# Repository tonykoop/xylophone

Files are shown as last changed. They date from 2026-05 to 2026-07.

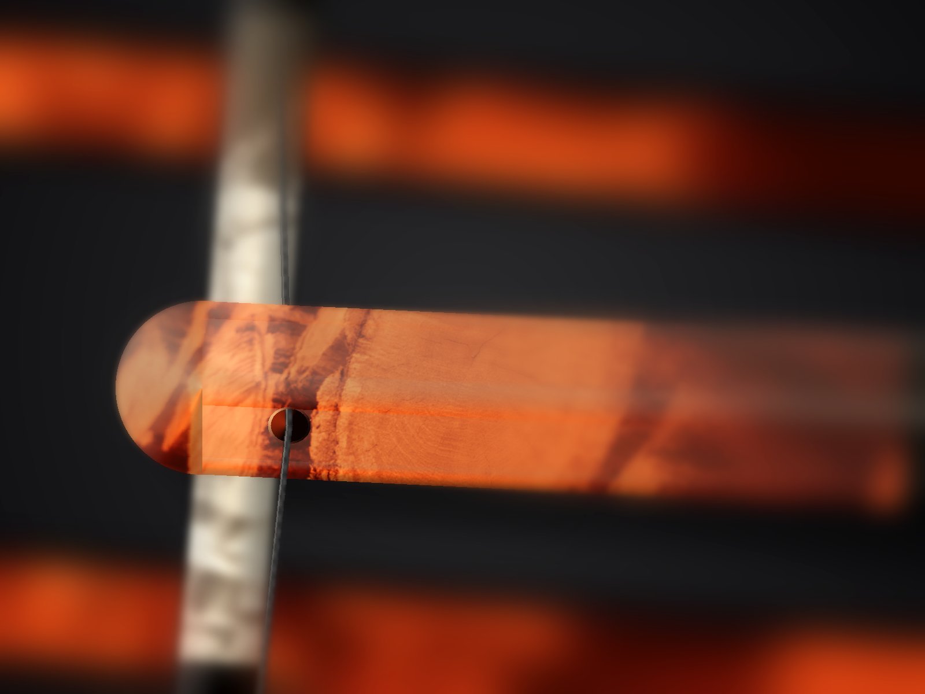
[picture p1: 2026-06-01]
images/macro/node-hole-suspension.png

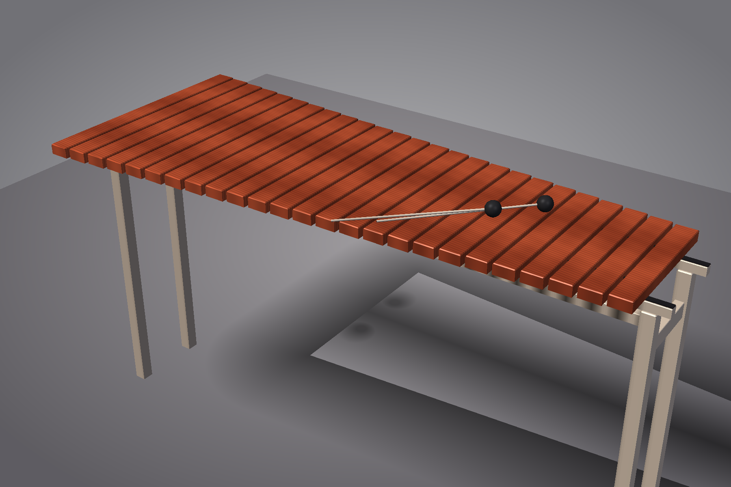
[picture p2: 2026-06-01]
images/hero-render.png

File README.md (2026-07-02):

# Xylophone

**Status:** L2 V5 build-packet candidate. Full design table, BOM, sourcing,
cut-list, and validation-loop gates exist for all 25 bars, but every bar
length, node-hole position, and resonator length is `measurement_required`
until a pilot bar is cut, tuned, mounted, and logged — see "Round 31 V5
Build-Packet Gate" below.

Xylophone hero — 25-bar chromatic in Padauk on a parametric trestle frame (placeholder)

A 25-bar chromatic xylophone, **C5 to C7**, in African Padauk on a
parametric trestle frame. Free-free flat-bar geometry, 12th-overtone
tuning convention, optional quarter-wave closed-pipe resonators
(deferred to v2). This repo is a v4.3 root-mode build packet from the
[`tonykoop/instrument-maker`](https://github.com/tonykoop/instrument-maker)
catalogue, designed deliberately as the *simpler sibling* of a future
`tonykoop/marimba` repo.

## Background

The xylophone is the higher-pitched cousin of the marimba: same
physics (free-free Euler-Bernoulli transverse beam vibration), harder
mallets, shorter bars, and a different second-mode tuning convention.
This packet ships the bar physics, the wood-species shortlist, the
suspension geometry, the validation workflow, and the build process
end-to-end. It deliberately *defers* the things that make a marimba
hard — the parabolic arch undercut, the mandatory tuned resonators,
the multi-octave frame — so the xylophone build is feasible in one
shop session and so the marimba follow-on can inherit a clean
scaffold rather than starting from scratch.

The root-of-truth design table is `xylophone-design-table.xlsx` at
the repo root. Every length, hole position, and resonator planning
length in `family-spec.csv` is solved from the parametric inputs
there, then held at `measurement_required` until a pilot bar is cut,
tuned, mounted, and logged.

## Design overview

- **Family:** 25 bars, C5 (523.25 Hz) through C7 (2093.00 Hz), chromatic.
- **Bar geometry:** flat-bottom rectangular, **1.500" × 0.875" cross
  section** held constant across the family. Length varies per note;
  see [`family-spec.csv`](family-spec.csv).
- **Wood:** **African Padauk** (sustainable, predictable acoustic
  properties, available in 4/4 quartersawn). Honduras Rosewood and
  Hard Maple are documented swap-ins.
- **Suspension:** 1/8" paracord through node holes drilled at 22.4%
  and 77.6% of bar length — the first free-free mode's nodes.
- **Tuning:** 12th-overtone convention noted as a *measurement
  target* on the validation sheet, not a CAD geometry. End-shaving
  is the production tuning method (no arch undercut — that's marimba).
- **Frame:** parametric 4-leg trestle, 21" wide × 30" tall, hard
  maple rails and legs with Baltic-birch corner gussets.
- **Resonators:** computed but optional. The L-per-note math is in
  `family-spec.csv` so adding resonators in v2 is additive; those
  lengths are not fabrication authority in this packet.

## Family-table preview (first and last)

| Note | Target Hz | Bar L (in) | Hole low (in) | Hole high (in) | Resonator L (in) | Mass (oz) |
|---|---|---|---|---|---|---|
| C5 | 523.25 | 16.683 | 3.737 | 12.946 | 5.22 | 9.43 |
| A4 * | 440.00 | n/a | n/a | n/a | n/a | n/a |
| A5 | 880.00 | 12.865 | 2.882 | 9.983 | 2.61 | 7.27 |
| C7 | 2093.00 | 8.342 | 1.869 | 6.473 | 0.38 | 4.71 |

\* A4 = 440 Hz is the standard tuning reference; the family ranges
from C5 upward, so A4 itself is not a member.

Full table: [`family-spec.csv`](family-spec.csv).

## Why this packet exists

This repo began as a v4.3 root-mode challenge run for the
[`instrument-maker`](https://github.com/tonykoop/instrument-maker)
skill and is now being held to the Round 31 V5 authority contract for a
wooden-idiophone build packet. Specifically:

1. Preserves the original root-mode packet shape while adding V5 readiness,
   validation-loop, and visual-authority gates.
2. Demonstrates the bar-idiophone branch of `acoustic-models.md`'s
   Free-Free Beams section with first-order honesty about K2 and
   end-correction guard rules.
3. Builds the design template that the marimba sister repo will
   inherit — every "marimba-equivalent: …" callout in
   [`design.md`](design.md) is a hook for the marimba build.

## Sister repos and references

- [`tonykoop/instrument-maker`](https://github.com/tonykoop/instrument-maker)
  — parent catalogue, the v4 skill source, references and scripts.
- [`tonykoop/tongue-drum`](https://github.com/tonykoop/tongue-drum) —
  closest sister repo: another wooden idiophone, free-free / cantilever
  beam math, SolidWorks master-layout convention, magazine-baseline
  attribution. The xylophone README borrows its structure.
- `tonykoop/marimba` *(planned)* — the natural follow-on; this
  packet's `design.md` calls out exactly what each marimba decision
  has to swap in (`Marimba-Equivalent Hooks` table).

## Repo layout

```
xylophone/
├── README.md                     ← this file
├── design.md                     ← governing model, family plan, decisions
├── family-spec.csv               ← parametric per-note table (25 rows)
├── bom.csv, sourcing.csv         ← parts and supplier candidates
├── cut-list.csv                  ← shop cut list (bars + frame)
├── validation.csv                ← measured-tuning workflow (8 rows)
├── validation-loop.csv           ← Round 31 measurement-required gates
├── visual-output-register.csv    ← visual/CAD/design-table authority register
├── drawings/per-bar-dxf-checklist.csv ← per-bar DXF release checklist
├── assembly-manual.md            ← 14-step shop manual
├── supplier-rfq.md               ← bar-stock RFQ template
├── drawing-brief.md              ← what the SVG drawings must show
├── visual-bom-brief.md           ← printable visual BOM brief
├── wolfram-starter.wl            ← parametric Wolfram source
├── risks.md                      ← red-team risk register
├── resources.md                  ← citations and references
├── jig-decision.md               ← three jig build/no-build calls
├── photo-shotlist.md             ← ten-shot photo plan
├── capstone-deck.md / .pptx      ← recruiter-facing slide deck
├── print-packet.md / .html / .pdf ← shop-printable packet
├── capstone-manifest.json        ← deck-and-packet manifest
├── xylophone-design-table.xlsx   ← parametric source of truth
├── images/                       ← hero, build photos
├── drawings/                     ← per-bar SVGs + frame elevation/plan
├── cad/                          ← SolidWorks master authority plan (master deferred);
│                                    cad/xylophone.scad parametric bar-schedule + frame envelope
├── cnc/                          ← cnc-plan.json + setup-sheet.md
├── jigs/                         ← jig sketches (deferred)
├── evolution/                    ← evolution-pipeline Stage 0 intake (Gate A not yet run)
└── site/                         ← static build-log site
```

## Round 31 V5 Build-Packet Gate

- This PR treats the repo as a V5/L1 build-packet candidate, not a
  bench-validated or build-ready instrument.
- `xylophone-design-table.xlsx` and `family-spec.csv` are the planning
  authority for first-order bar dimensions and node-hole positions.
- `visual-output-register.csv` records that the hero placeholder and SVG
  previews are not fabrication authority.
- `validation-loop.csv` names the pilot-bar, resonator, frame/CNC, and visual
  authority gates that must close before any L2 or shop-release claim.
- Empirical/build gates remain deferred until pilot bars are cut, measured,
  tuned, mounted, and logged in `validation.csv`.

## Round 33C/D CAD/DXF Authority Gate

- `cad/solidworks-master-authority-plan.md` defines the future SolidWorks
  master-layout and extracted-dimension CSV gate; it is not CAD authority by
  itself.
- `drawings/per-bar-dxf-checklist.csv` lists all 25 bars and the per-bar DXF
  checks required before any DXF can become shop authority.
- Per-bar DXF release remains blocked until pilot-bar V2/V3 measurements exist,
  exported CAD dimensions match the reviewed table, and the released artifacts
  are recorded in `visual-output-register.csv`.

## License

[CC BY 4.0](LICENSE) — see LICENSE for details.

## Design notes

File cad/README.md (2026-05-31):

# Xylophone — CAD

SolidWorks master-layout part lives here once built. The convention
mirrors the **tongue-drum** sister repo (`tongue-drum/cad/`): a single
`*_MasterLayout.SLDPRT` part with all design-table parameters, an
assembly that references the master, and a dimensions-extract macro
that emits a CSV for round-trip validation against the Excel design
table.

## Status: not yet built

The parametric design table is **already** authored in
`xylophone-design-table.xlsx` at the repo root, and the math is
operationalized in `family-spec.csv` and `wolfram-starter.wl`.
Building the SolidWorks model is the next CAD-side step; the
gating row in `validation.csv` is V2 (post-cut measurement) — once
real measured data exists, the model can be built with confidence
that the parametric inputs are calibrated.

Round 33C/D adds `solidworks-master-authority-plan.md` as the CAD release
contract. It names the intended SolidWorks files, extracted-dimension CSV, and
review gates, but it does not add a SolidWorks master or promote any DXF/CAD
artifact to fabrication authority.

## Naming convention (when built)

- `XYL-001_MasterLayout.SLDPRT` — single master part, design table
  inside, all family-table inputs as global variables.
- `XYL-001_Xylophone.SLDASM` — assembly referencing the master, one
  configuration per family member.
- `Extract_Xylophone_Dimensions_AllConfigs.bas` — macro per the
  tongue-drum precedent. Output: `*_dimensions.csv` for ingest by
  `scripts/ingest_dimension_csv.py`.

## Reference

- `tongue-drum/cad/Extract_Dimensions.swp` — binary macro to copy
  and adapt.
- `tongue-drum/cad/TNG-000_MasterLayout.xlsx` — design-table
  layout exemplar.
- `references/solidworks-integration.md` — the three pillars of
  Tony's SW workflow (global equations, design tables, master sketch).
- `xylophone-design-table.xlsx` — the existing input source. Don't
  duplicate; reference.
- `solidworks-master-authority-plan.md` — local gate for future master-layout,
  extracted-dimension, and per-bar DXF release.
- `../drawings/per-bar-dxf-checklist.csv` — per-bar review checklist to complete
  before any generated DXF is treated as shop authority.

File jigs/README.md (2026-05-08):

# Xylophone — Jigs

Three jig decisions documented in `jig-decision.md`. Two are build,
one is no-build. Build sketches live here; finished jig drawings
are added once the jigs themselves are built.

## Index

| Jig | Decision | Sketch |
|---|---|---|
| Node-hole drilling jig | **BUILD**  | `node-hole-drilling-jig.md` (TBD) |
| Bar-end-shaving sled | **BUILD**  | `bar-end-shaving-sled.md` (TBD) |
| Frame-rail miter sled | NO BUILD | n/a (use existing miter saw) |

## Status

Sketches are TBD. The build-recommendation rationale is captured
in `jig-decision.md`; the jigs themselves are bench-built before
shop step 5 (drilling) and step 7 (end-shaving) of
`assembly-manual.md`. Photograph each jig once built and add the
image link to this README.

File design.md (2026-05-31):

# Xylophone — Design

A 25-bar chromatic xylophone, C5 to C7, in Padauk on a parametric trestle frame.
Free-free flat-bar geometry, 12th-overtone tuning convention, optional
quarter-wave closed-pipe resonators (deferred). Designed deliberately as the
*simpler* sibling of a future marimba sister repo: every place this design
chooses the simpler path, the marimba-equivalent is documented inline so the
marimba scaffold inherits cleanly.

## Intent

Ship a parametric, validator-clean, public-readable Mode A build packet for
a serious wooden tuned-bar idiophone — small enough to build in one shop
session, honest enough about the physics that the predicted frequencies and
the measured frequencies will disagree on first cut and the workflow can
correct them, structured enough that a marimba follow-on can reuse the
family table, the validation rows, the suspension geometry, the SolidWorks
master-layout convention, and the empirical-correction guard rules.

The reader should leave with: (a) a parametric design table whose inputs
are wood species, bar thickness, target pitch, and frame geometry; (b) a
defensible first-order frequency prediction per note; (c) a measured-tuning
workflow that closes the loop on the prediction; (d) a clear "this is what
turns into marimba next" map.

## Governing Model

Free-free Euler-Bernoulli transverse beam vibration, first mode:

    f_1 = 1.028 × (h / L²) × √(E / ρ)

Symbols and units (SI):

- `h` — bar thickness (m)
- `L` — bar length (m)
- `E` — Young's modulus along grain (Pa)
- `ρ` — density (kg/m³)
- `f_1` — first-mode frequency (Hz)

Reference: `acoustic-models.md` Free-Free Beams section. The formula
follows from `K_free_free ≈ 6.36 × K_cantilever` applied to the
cantilever form `f_1 ≈ 0.162 × (h/L²) × √(E/ρ)`. Suspension nodes for
the first free-free mode are at **22.4% and 77.6% of L** — every
cord-hole in `family-spec.csv` is placed there.

**First-order estimate caveat.** Per the `acoustic-models.md`
empirical-correction guard rules, K2 corrections, scale-offset tables,
and end-corrections **do not apply** to bar idiophones. Material
K-constants from the cantilever wood table are species-specific and
only valid for the free-free / fixed-free regime — they propagate to
this packet via the 6.36× factor above. Every predicted frequency in
`family-spec.csv` is flagged as *first-order*; `validation.csv` is the
mechanism that closes the gap with measured data after first prototype.
Round 31 keeps this packet at `L1_packet -> measurement_required` until
that loop has actual tuner evidence.

**Xylophone tuning convention.** Bars are tuned to align the *12th
overtone* (3:1 frequency ratio above the fundamental — actually the
second flexural mode tuned to a perfect 12th of the fundamental in the
concert convention; first-order math reports `f_1` only). Marimba
tunes the second mode to a 4:1 ratio (two octaves) by parabolic arch
undercut. **This packet uses no arch undercut** — bars are flat-bottom
rectangular blanks, end-shaved for fundamental tuning. The
12th-overtone target is documented as a *measurement target* in
`validation.csv`, not a CAD geometry — adjust at the bench.

> Marimba-equivalent: replace the flat-bottom geometry with a parabolic
> CNC arch on the underside (`acoustic-models.md`:
> `center_thickness = edge_thickness × (target_freq / flat_bar_freq)²`,
> minimum center 0.25"). Replace the 12th-overtone target with the
> 4:1 octave-and-a-fifth target. Replace the optional resonators with
> mandatory tuned tubes.

## Family Plan

Two octaves chromatic, C5 to C7, 25 bars. Family geometry held
constant: bar width `W = 1.500"`, bar thickness `h = 0.875"` (7/8"
flat stock). Only `L` varies — solved per note from the governing
model. See `family-spec.csv` for the full table.

Predicted lengths run from **16.683" at C5** to **8.342" at C7**.
These are noticeably longer than a concert xylophone of the same
range because the design has no arch undercut — the arch is what
lets a concert xylo hit the same pitch with a 10–12" bar. The
flat-bar tradeoff is honest, parametric, and easier to first-cut.

Width and thickness are constants in this v1 family. Production
xylophones often taper width across the range; that's a deferred
optimization, called out in Open Assumptions.

> Marimba-equivalent: keep width constant within an octave but step
> width up at register boundaries (low marimba bars are wider). Add an
> arch-depth column. Add a resonator-tube-bore column.

## Wood Species

Three-tier shortlist; **Padauk is the spec's primary** because it is
sustainably sourced, has predictable acoustic properties, machines
cleanly, and is widely available in 4/4 quartersawn:

| Tier | Species | E (GPa) | ρ (kg/m³) | √(E/ρ) (m/s) | Notes |
|---|---|---|---|---|---|
| Primary | African Padauk | 12.6 | 745 | 4112 | Spec default. Stable, predictable, sustainable. |
| Traditional | Honduras Rosewood | 14.1 | 1000 | 3756 | Concert standard. **CITES II** — sourcing risk. |
| Educational/budget| Hard Maple | 12.6 | 705 | 4229 | Cheapest, most available, dampest sound. |

Switching the primary requires a single edit in
`xylophone-design-table.xlsx` (input cell `wood_species`); the family
table re-solves automatically. The validator runs on the table's
current state, not on a hardcoded snapshot.

> Marimba-equivalent: same shortlist, but most concert marimbas use
> Padauk or Honduras Rosewood; Birch is the educational tier.

## Tuning Workflow

The validation loop has eight rows in `validation.csv`. Two are
prediction-only; six require a tuner and a chromatic environment log:

1. Rough-cut prediction (paper, before any cut).
2. Post-cut fundamental measurement (immediately after bandsaw + plane).
3. Post-shave measurement (after end-shaving for fundamental tune).
4. Post-finish measurement (after oil/wax — finish adds mass, drops pitch).
5. Post-resonator-install measurement (when resonators are installed; deferred).
6. 30-day moisture re-measure (drift after first shop cycle).
7. 60-day moisture re-measure (drift after a full season cycle).
8. Full-octave evenness check (every C across both octaves on the same day).

Each row carries `tuner_make_model`, `temp_F`, `humidity_RH_percent`,
and `cents_target` columns matching `record_measurement.py`'s schema.
A measured Hz feeds `record_measurement.py --packet . --note-id <X>
--measured-hz <f>` and the per-family corrections database absorbs
the delta.

## Resonator Decision

**Optional, deferred to v2 build.** The L-per-note math is computed
in `family-spec.csv` (column `resonator_l_in_optional`) using the
quarter-wave closed-pipe formula with end correction:

    L_resonator = c / (4 f) − 0.82 × bore

with `c = 343 m/s` and `bore = 1.500"`. Lengths run from **5.22" at
C5** down to **0.38" at C7**. The high-end values are too short to
build practically — the production decision will be: tune resonators
on bars at C5 through approximately G5 (lengths > 3"), and skip
resonators on the upper octave. This decision is made when resonators
are installed, not now; the `resonator_l_in_optional` column is a
planning field only.

> Marimba-equivalent: resonators are mandatory; the bore is bigger
> (typically 2.0–3.0"); each tube is plugged at the bottom and tuned
> at the top end. Marimba tubes are also typically *not* trimmed by
> the 0.82×bore end-correction directly — they're trimmed by ear at
> the bench.

## Frame Layout

4-leg parametric trestle frame, two suspension rails running the full
length of the bar fan. Rail length sized to `max(family-spec L) +
4" margin = 16.683 + 4 = 20.683"` rounded up to **21"**. Leg
height **30"** (standard standing-play height; sit-down play needs
a swap to 24"). Cord suspension with `1/8"` paracord through the
node holes; cord termination at the rail ends with a tied-loop and
finish washer.

Frame parts are CNC candidates (rails, leg blanks, gussets) — see
`cnc/operations.csv`. Bars are explicitly out of CNC scope: bandsaw
to rough → surface plane to thickness → drum-sand surfaces → drill
node holes (jig) → end-shave for tuning (manual). The CNC plan
states this exclusion in the setup sheet.

> Marimba-equivalent: longer frame (4-octave marimba is 5+ feet),
> resonator wells underneath each bar pair, height-adjustable legs,
> traveling-cart casters.

## Mallets

Hard rubber → lexan → rosewood-head shortlist. Hard mallets are
appropriate for xylophone (the percussive, glassy attack is part of
the instrument's voice). They are **harder than marimba mallets**
and *can* crack a softer-wood bar — see `risks.md` entry
`bar-cracking-from-hard-mallets`. Standard practice: yarn-wrapped
mallets for low octave, lexan/rubber for upper. v1 packet ships with
hard rubber as the recommended starter; lexan and rosewood are
swap-ins.

> Marimba-equivalent: yarn-wrapped soft mallets across the entire
> range. The bars are softer (Honduras Rosewood is a hardwood but
> with arch undercut the center is thin); soft mallets prevent
> cracking and produce a warmer overtone profile.

## Marimba-Equivalent Hooks (summary map)

| Decision | Xylophone (this packet) | Marimba (sister repo, deferred) |
|---|---|---|
| Bar geometry | Flat-bottom rectangular | Parabolic arch undercut on underside |
| Tuning ratio target | 12th overtone (3:1) | 4:1 (two octaves) |
| Resonators | Optional, deferred | Mandatory, tuned per bar |
| Bar width policy | Constant 1.500" across range | Step up at register boundaries |
| Mallet hardness | Hard rubber → lexan → rosewood | Yarn-wrapped soft → medium |
| Suspension cord | 1/8" paracord | 3/16" or 1/4" (heavier bars) |
| Frame length | 21" rail | 60"+ rail, multi-octave |
| Wood primary | Padauk | Padauk or Honduras Rosewood |

A future `marimba/` repo can `cp -r xylophone/* marimba/` and edit
exactly these eight rows in the design table to bootstrap.

## Open Assumptions

1. **No measured data yet.** Every frequency in `family-spec.csv` is a
   first-order prediction. First measurement after first prototype is
   the single most important next step. (`validation.csv` row 2.)
2. **Wood species.** Padauk is the primary by spec choice; Honduras
   Rosewood and Hard Maple swap in by changing one cell in the
   workbook. CITES sourcing for HR is not analyzed in this packet.
3. **Family range.** C5–C7 chromatic is the chosen default. F4–F6
   diatonic and G4–G6 diatonic remain documented alternatives — they
   trade range for shorter bar stock and a smaller frame.
4. **Bar thickness held constant at 7/8".** A real production xylo
   often steps thickness up in the low octave to keep bars from being
   absurdly long. This packet keeps thickness constant for parametric
   simplicity and accepts the 16.7" C5 bar.
5. **Resonator strategy.** The L-per-note math is computed but
   resonators are not specified in the BOM. Adding them is additive,
   not breaking — the frame design leaves vertical clearance.
6. **CAD.** SolidWorks master-layout part is deferred; the
   `cad/` folder now includes `solidworks-master-authority-plan.md`
   naming the future master-layout, extracted-dimension CSV, and
   per-bar DXF release gates. This is an authority plan only, not
   a CAD release.
7. **Mallet supplier.** v1 lists generic hard-rubber mallets; specific
   supplier (Innovative Percussion vs Encore vs Vic Firth) is not
   selected.
8. **Visual authority.** `images/xylophone-hero-placeholder.svg` and
   `drawings/template.svg` are concept or preview aids. Fabrication authority
   stays with the design table and reviewed measurement records until
   per-bar drawings are generated from the table, checked against
   `drawings/per-bar-dxf-checklist.csv`, and recorded in the visual register.

These rows are exactly the assumptions the handoff report
flags. Each becomes a `validation.csv` or `bom.csv` line item once
the gating decision is made.

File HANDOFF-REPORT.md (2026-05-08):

# Xylophone — v4.3 Root-Mode Packet Handoff Report

**Date:** 2026-05-08
**Skill:** instrument-maker-v4 (v4.3 release candidate)
**Mode:** A (root-mode), Mode A repo at `C:\Users\Tony\Documents\GitHub\xylophone`

## 1. Validator status

**`scripts/validate_packet.py --mode root --json` → `ok: true`, zero findings.**

```json
{
  "layout": "root",
  "pass_1_findings": [],
  "fixes_applied": [],
  "pass_2_findings": null,
  "findings": [],
  "ok": true
}
```

All Tier 1 deliverables present: `design.md`, `bom.csv`,
`sourcing.csv`, `cut-list.csv`, `validation.csv`, `assembly-manual.md`,
`supplier-rfq.md`, `drawing-brief.md`, `visual-bom-brief.md`,
`wolfram-starter.wl`, `risks.md`, `capstone-deck.md`,
`capstone-deck.pptx`, `print-packet.md`, `print-packet.html`,
`print-packet.pdf`, `capstone-manifest.json`, `README.md`.

v4.3 adjuncts present: `family-spec.csv`, `photo-shotlist.md`,
`resources.md`, `jig-decision.md`, `cnc/cnc-plan.json`,
`cnc/operations.csv`, `cnc/setup-sheet.md`, `cad/README.md`,
`jigs/README.md`, `drawings/template.svg`, `site/index.html`,
`images/xylophone-hero-placeholder.svg`.

**Smoke checks (independent of validator):**

- `README.md` = 6,493 bytes (≥2,000 byte threshold).
- `family-spec.csv` = 26 lines (header + 25 chromatic notes C5–C7).
- `design.md` `## Intent` heading present (deck regex hit).
- `risks.md` has 7 risk entries spanning all five required categories.
- `capstone-deck.md` has 14 slides (≥12 threshold).
- `capstone-manifest.json` parses cleanly.
- `site/index.html` is valid HTML with `<title>Xylophone — Design — Tony Koop's Build Log</title>`.
- `capstone-deck.pptx` 48.7 KB, `print-packet.pdf` 90.6 KB — both
  generated end-to-end (python-pptx and reportlab were already
  installed in this env, so the planned degradation case did not
  trigger).

## 2. Unresolved assumptions

| Assumption | Status | What would resolve it |
|---|---|---|
| No measured tuning data | Open | First prototype build → measure post-cut frequencies → run `record_measurement.py` |
| Wood species (Padauk default) | Open | Confirm sustainable Padauk supplier or switch in HR / Hard Maple in xlsx |
| Family range C5–C7 chromatic | Confirmed| User-selected during plan-mode intake; F4–F6 / G4–G6 documented as alternatives |
| Bar thickness held constant 7/8" | Open | Production xylo often steps thickness up at low octave — re-examine post v1 build  |
| Resonator strategy | Deferred | Optional in v1; tube-installation flow lives in `validation.csv` row V5 |
| CAD master | Deferred | Build SolidWorks master per tongue-drum convention after first measured build |
| Mallet supplier choice | Open | RFQ to Innovative Percussion / Encore / Vic Firth; no pick yet |

The biggest of these by far is **no measured data**. Every Hz in
`family-spec.csv` is a first-order Euler-Bernoulli prediction with the
*first-order estimate* caveat baked into the design.md, the wolfram
package, and the validation.csv. Closing this assumption requires
shop time, not desk time.

## 3. Jig and frame decisions

From `jig-decision.md`:

- **Node-hole drilling jig — BUILD.** 50 holes total at ±1/32" tolerance;
  flip-stop fixture pays back on bar #4–5.
- **Bar-end-shaving sled — BUILD.** Shaving must be square and
  parallel; a shooting sled makes both automatic.
- **Frame-rail miter sled — NO BUILD.** 8 miters total; the existing
  miter saw with a sharp 80T blade is enough.

**Frame:** parametric 4-leg trestle, 21" wide × 30" tall, hard-maple
rails and legs with Baltic-birch corner gussets. Rationale: simplest
shape that resolves all four xylophone constraints (longest bar
clearance, standard standing-play height, suspension cord termination,
shop-buildable in one session).

## 4. Measured-validation needs

`validation.csv` defines eight rows that need shop time to close out:

| Row | Phase | Note(s) | Trigger |
|-----|---|---|---|
| V1  | prediction-paper | ALL | already done (in spec) |
| V2  | post-cut | A5 representative | first prototype bandsaw + plane |
| V3  | post-shave | A5 | end-shave to fundamental |
| V4  | post-finish | A5 | 24h after final tung-oil |
| V5  | post-resonator-install | A5 | deferred to v2 build |
| V6  | 30-day-moisture | ALL | 30 days post-finish |
| V7  | 60-day-moisture | ALL | 60 days post-finish |
| V8  | full-octave-evenness | C5, C6, C7 | one-session evenness check |

The closure workflow per row: capture Hz with the Korg OT-120, log
`temp_F` + `humidity_RH_percent`, then run

```bash
python3 scripts/record_measurement.py \
  --packet /mnt/c/Users/Tony/Documents/GitHub/xylophone \
  --note-id A5 --measured-hz <observed> \
  --tuner "Korg OT-120" --environment "shop, 68F, 45% RH"
```

The script computes cents error vs the prediction, appends to the
per-family corrections database, and flags any sibling packets in the
same family whose predictions just shifted by more than 2 cents — at
launch the only sibling that will exist is the future marimba repo,
which means xylophone measurements will start *seeding* the marimba
predictions before marimba is even built.

## 5. Marimba stepping-stone fitness — confidence: HIGH

This packet was deliberately authored as the marimba repo's scaffold.
Three concrete hooks:

1. **Same governing model.** Free-free Euler-Bernoulli with the
   `K_free_free ≈ 6.36 × K_cantilever` factor. Marimba's only physics
   addition is the **arch undercut** geometry (parabolic CNC cut on
   the underside, formula explicitly cited in `design.md`'s
   "Marimba-equivalent" callout under Bar Geometry). The undercut
   *modifies* the predicted f₁ — it doesn't replace the model.
2. **Same family-spec contract.** `family-spec.csv` columns
   (`note,target_hz,bar_length_in,bar_width_in,bar_thickness_in,
   hole_pos_low_in,hole_pos_high_in,predicted_f1_hz,predicted_f1_source,
   wood_species,resonator_l_in_optional,mass_oz_est,notes`) all
   transfer to marimba. Marimba adds two columns:
   `arch_center_thickness_in` and `resonator_l_in_required`.
3. **Same validation workflow.** The eight-row schema in
   `validation.csv`, including the 30/60-day moisture rows, the
   tuner spec, and the `record_measurement.py` flow — all
   inherited verbatim. Marimba's only addition is a `post-arch-cut`
   measurement row between V2 and V3.

The `Marimba-Equivalent Hooks` table in `design.md` is the explicit
delta map: 8 rows, each one a single editable cell that turns the
xylophone packet into a marimba scaffold. A `cp -r xylophone/* marimba/`
followed by edits to those 8 rows + adding the arch-undercut math
section is the smallest viable bootstrap path.

**Recommendation:** before starting `marimba/`, build at least the V2
and V3 rows of this packet's `validation.csv` on a real Padauk bar.
That measurement ratio (predicted vs measured for a flat free-free
bar) is the *empirical anchor* both repos will share, and it should
exist before the marimba repo's predictions are computed against it.

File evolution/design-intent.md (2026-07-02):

# Design Intent — xylophone rev A

- Master CAD: `cad/xylophone.scad` (sha256: bffea1571ad04a29865a15cf72456fba2f012f93da7229aa9ad8fb3eb6ef3918), driven by `xylophone-design-table.xlsx` (sha256: 01b4556e8925f5cd1ec137b044a481305ed52c24df1608c4a3ef1d7126a91e23)
- Function: 25-bar chromatic xylophone, C5 (523.25 Hz) to C7 (2093.00 Hz), African Padauk flat-bottom bars on a 4-leg parametric trestle frame. Free-free Euler-Bernoulli transverse beam vibration (`f1 = 1.028*(h/L^2)*sqrt(E/rho)`); 1/8" paracord suspension through node holes at the free-free first mode's node fractions (22.4%/77.6% of bar length); 12th-overtone tuning convention is a measurement target, not CAD geometry (design.md).
- Environment: struck idiophone, indoor/studio use; end-shaving is the production tuning method (manual, post-cut).
- Target qty: 1 (prototype, deliberately simpler sibling of a planned marimba repo). Deadline: TBD. Budget/unit ceiling: TBD.

## Critical dimensions (carry tolerances)

| Feature | Nominal | Tolerance | Why critical | Source |
| --- | --- | --- | --- | --- |
| Bar cross section | 1.500 x 0.875 in (constant across family) | held constant | sets predicted f1 via Euler-Bernoulli formula | family-spec.csv (design.md) |
| Bar length (per note, 25 rows) | 16.683 in (C5) down to 8.342 in (C7) | measurement_required — pilot bar V2 gate | primary pitch-setting dimension | family-spec.csv `bar_length_in` |
| Node hole positions (per bar) | 22.4% / 77.6% of bar length | measurement_required | suspension nodes for the first free-free mode; wrong position kills sustain | family-spec.csv `hole_pos_low_in`/`hole_pos_high_in` |
| Rail length | 21.000 in | fixed (= max bar L + 4in margin, rounded) | frame must span the longest (C5) bar | design.md "Frame Layout" / cut-list.csv RAIL-L/R |
| Leg height | 30.000 in | standing-play height (24in swap for sit-down) | ergonomics | design.md "Frame Layout" / cut-list.csv LEG-* |

## Incidental (free for DFM)

- Frame corner gusset shape, finish/oil sheen, bar edge chamfer cosmetic profile, cord color.

## Must-nots (DFM may never violate)

- Do not treat any predicted_f1_hz value in family-spec.csv as tuned — it is a first-order Euler-Bernoulli estimate; end-shaving against a tuner is the actual tuning step (design.md, validation.csv).
- Do not add an arch/undercut to the bar profile — this is explicitly the flat-bar "simpler sibling"; arch tuning is out of scope and reserved for the planned marimba repo (design.md "Marimba-Equivalent Hooks").
- Do not promote resonator lengths (family-spec.csv `resonator_l_in_optional`) to fabrication authority — resonators are deferred to v2 and explicitly not fabrication authority in this packet (design.md).
- Bars are explicitly out of CNC scope (bandsaw → plane → sand → drill node holes via jig → hand end-shave) — do not route/CNC-cut the bars themselves (design.md "Frame Layout").

## Material intent

- Bars: African Padauk (E=12.6 GPa, rho=745 kg/m3), 4/4 quartersawn. Documented swap-ins: Honduras Rosewood, Hard Maple.
- Frame: Hard maple rails/legs, Baltic-birch plywood corner gussets.
- Forbidden: none recorded.

## Stage status

Stage 0 intake complete 2026-07-01. Gate A (Alpha shop compile) NOT yet run — no concessions logged, nothing presented as shippable.

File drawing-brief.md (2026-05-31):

# Xylophone — Drawing Brief

What the SVG and CAD drawings need to show, in priority order. The
drawings live in `drawings/` (per-family-member SVGs and a frame
elevation/plan); the CAD master lives in `cad/` once built.

## DR-01: Bar template (parametric)

A single dimensioned drawing template that varies per family member.
**Critical dimensions:**

- Bar length `L` (from `family-spec.csv` per note).
- Bar width `W = 1.500"`.
- Bar thickness `h = 0.875"` (section view).
- Node-hole positions: low-side at `0.224 × L`, high-side at
  `0.776 × L`. Hole diameter `1/8"`.
- Strike line at center (`L/2`) — annotation only, not a feature.
- Edge round-over `1/16"` on all four long edges.

Title block must show: drawing ID, note name, family `XYL`, scale
(1:2 reads cleanly for the long bars), revision, date, designer,
material, finish.

The drawing template's only variable is `L` and the two derived hole
positions. A generator should be able to produce 25 SVGs from the
family table by string substitution alone.

## DR-02: Frame elevation

Side view of the assembled frame (no bars). Shows:

- Two suspension rails, `21.000" × 2.250" × 1.250"`, mounted on top
  of the legs.
- Four legs, `30.000" × 1.500" × 1.500"`. Chamfered top edge.
- Corner gussets, `6.000 × 6.000 × 0.500"` plywood, on the inside
  face of each leg-rail joint.
- Cord-suspension geometry — schematic, not dimensioned.
- Overall envelope: 21" wide, 30" tall.

## DR-03: Frame plan

Top view of the frame with bars laid in suspension. Shows:

- Both rails parallel, 6.5" inside-to-inside.
- 25 bar positions in the family-table order, lowest at the left.
- Inter-bar gap: 0.250" minimum.
- Total bar-array length: ~17" (driven by the longest bar plus
  gaps).
- Cord routing: alternating side-to-side through node holes.

## DR-04: Mallet detail

Three-view of the recommended hard-rubber mallet (from `bom.csv`).
Shaft length, head diameter, head shape. **Reference only** — the
mallets are purchased, not built. Goes on the visual BOM, not in
the build instructions.

## Style notes

- All dimensions in inches. Decimal, three places (`16.683`),
  consistent with `family-spec.csv` and `cut-list.csv`.
- Datum chain: bar drawings reference left bar end; frame drawings
  reference left-rear leg base.
- Tolerances: bars ±1/64", frame ±1/32" (frame loose on purpose —
  bars do the precision work).
- File names: `drawings/DR-01-bar-<note>.svg` per bar (or a single
  `drawings/template.svg` until the per-bar instances are
  generated). Frame drawings: `drawings/DR-02-frame-elevation.svg`,
  `drawings/DR-03-frame-plan.svg`. Mallet: `drawings/DR-04-mallet.svg`.

## Generator hookup

A future invocation of `scripts/generate_drawings.py` against this
packet will populate `drawings/DR-01-bar-*.svg` from `family-spec.csv`.
Until that runs, `drawings/template.svg` is the placeholder showing
the title-block layout and the datum chain so the generator's output
matches in style.

## Round 31 Authority Note

`drawings/template.svg` is a derived preview, not a shop-release drawing.
Before cutting bars from drawings, generate the per-bar SVGs from
`xylophone-design-table.xlsx` / `family-spec.csv`, review the node-hole
positions against the selected pilot-bar measurements, and update
`visual-output-register.csv` so the drawing authority chain remains explicit.

## Round 33C/D DXF Authority Note

`drawings/per-bar-dxf-checklist.csv` is the release checklist for future
per-bar DXF exports. A DXF file is not shop authority until its row is marked
reviewed after:

- the A5 pilot-bar V2/V3 measurement loop is recorded;
- the SolidWorks master or equivalent CAD generator has exported dimensions
  back to CSV;
- the exported dimensions match `family-spec.csv` or a reviewed replacement
  design table;
- the DXF uses inch units and the required `FAB_GEOMETRY`, `DATUM`,
  `DIMENSION`, and `NOTES` layers;
- `visual-output-register.csv` records the released DXF/CAD artifact.

Until those checks close, `drawings/template.svg`, any generated per-bar SVG,
and any future DXF remain previews derived from first-order design-table data,
not measured bar readiness.

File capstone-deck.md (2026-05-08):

# Xylophone Capstone
- Musical instrument documentation capstone
- Build packet: xylophone
- Generated: 2026-05-08

---

# Project Intent
- Ship a parametric, validator-clean, public-readable Mode A build packet for
a serious wooden tuned-bar idiophone — small enough to build in one shop
session, honest enough about the physics that the predicted frequencies and
the measured frequencies will disagree on first cut and the workflow can
correct them, structured enough that a marimba follow-on can reuse the
family table, the validation rows, the suspension geometry, the SolidWorks
master-layout convention, and the empirical-correction guard rules.

_Speaker notes:_ Read design.md before committing to dimensions or sourcing decisions.

---

# Physics Model
- Free-free Euler-Bernoulli transverse beam vibration, first mode:

_Speaker notes:_ Governing equations extracted verbatim from design.md. Apply empirical corrections (NAF K2, scale offsets) only where the model permits — see references/acoustic-models.md.

---

# How To Use This Packet
- Start with design.md for intent and assumptions.
- Use bom.csv, sourcing.csv, and cut-list.csv before buying or cutting.
- Use drawing-brief.md and CAD/CNC folders before machining.
- Print the packet for shopping, shop work, and validation.

---

# File Map
- design.md: Project intent, catalog metadata, assumptions, and validation plan.
- bom.csv: Starter bill of materials with part categories, quantities, drawing refs, and notes.
- sourcing.csv: Supplier/search tracker with specs, price/date fields, lead time, substitutes, and risks.
- cut-list.csv: Rough/final stock sizes, material, grain/orientation, operations, yield, and offcuts.
- drawing-brief.md: Manufacturing drawing and technical product sketch brief.
- assembly-manual.md: Shop-facing sequence, tools, fixtures, safety, tuning, finishing, and maintenance notes.
- validation.csv: Target/measured values, tolerance, environment, result, and tuning/build action log.
- supplier-rfq.md: Supplier email/request-for-quote starter.

---

# Family Spec

| note | target_hz | bar_length_in | bar_width_in | bar_thickness_in | hole_pos_low_in | hole_pos_high_in | predicted_f1_hz | predicted_f1_source | wood_species | resonator_l_in_optional | mass_oz_est | notes |
| --- | --- | --- | --- | --- | --- | --- | --- | --- | --- | --- | --- | --- |
| C5 | 523.25 | 16.683 | 1.500 | 0.875 | 3.737 | 12.946 | 523.25 | free-free Euler-Bernoulli f1=1.028(h/L^2)sqrt(E/rho); first-order; Padauk E=12.6GPa rho=745kg/m3 | Padauk | 5.22 | 9.43 | solved L from target_hz |
| C#5 | 554.37 | 16.208 | 1.500 | 0.875 | 3.631 | 12.578 | 554.37 | free-free Euler-Bernoulli f1=1.028(h/L^2)sqrt(E/rho); first-order; Padauk E=12.6GPa rho=745kg/m3 | Padauk | 4.86 | 9.16 | solved L from target_hz |
| D5 | 587.33 | 15.747 | 1.500 | 0.875 | 3.527 | 12.220 | 587.33 | free-free Euler-Bernoulli f1=1.028(h/L^2)sqrt(E/rho); first-order; Padauk E=12.6GPa rho=745kg/m3 | Padauk | 4.52 | 8.90 | solved L from target_hz |
| D#5 | 622.25 | 15.299 | 1.500 | 0.875 | 3.427 | 11.872 | 622.25 | free-free Euler-Bernoulli f1=1.028(h/L^2)sqrt(E/rho); first-order; Padauk E=12.6GPa rho=745kg/m3 | Padauk | 4.20 | 8.65 | solved L from target_hz |
| E5 | 659.26 | 14.863 | 1.500 | 0.875 | 3.329 | 11.534 | 659.26 | free-free Euler-Bernoulli f1=1.028(h/L^2)sqrt(E/rho); first-order; Padauk E=12.6GPa rho=745kg/m3 | Padauk | 3.89 | 8.40 | solved L from target_hz |
| F5 | 698.46 | 14.440 | 1.500 | 0.875 | 3.235 | 11.205 | 698.46 | free-free Euler-Bernoulli f1=1.028(h/L^2)sqrt(E/rho); first-order; Padauk E=12.6GPa rho=745kg/m3 | Padauk | 3.60 | 8.16 | solved L from target_hz |
| F#5 | 739.99 | 14.029 | 1.500 | 0.875 | 3.142 | 10.886 | 739.99 | free-free Euler-Bernoulli f1=1.028(h/L^2)sqrt(E/rho); first-order; Padauk E=12.6GPa rho=745kg/m3 | Padauk | 3.33 | 7.93 | solved L from target_hz |
| G5 | 783.99 | 13.630 | 1.500 | 0.875 | 3.053 | 10.577 | 783.99 | free-free Euler-Bernoulli f1=1.028(h/L^2)sqrt(E/rho); first-order; Padauk E=12.6GPa rho=745kg/m3 | Padauk | 3.08 | 7.70 | solved L from target_hz |
| G#5 | 830.61 | 13.242 | 1.500 | 0.875 | 2.966 | 10.275 | 830.61 | free-free Euler-Bernoulli f1=1.028(h/L^2)sqrt(E/rho); first-order; Padauk E=12.6GPa rho=745kg/m3 | Padauk | 2.83 | 7.48 | solved L from target_hz |
| A5 | 880.00 | 12.865 | 1.500 | 0.875 | 2.882 | 9.983 | 880.00 | free-free Euler-Bernoulli f1=1.028(h/L^2)sqrt(E/rho); first-order; Padauk E=12.6GPa rho=745kg/m3 | Padauk | 2.61 | 7.27 | solved L from target_hz |
| A#5 | 932.33 | 12.498 | 1.500 | 0.875 | 2.800 | 9.699 | 932.33 | free-free Euler-Bernoulli f1=1.028(h/L^2)sqrt(E/rho); first-order; Padauk E=12.6GPa rho=745kg/m3 | Padauk | 2.39 | 7.06 | solved L from target_hz |
| B5 | 987.77 | 12.143 | 1.500 | 0.875 | 2.720 | 9.423 | 987.77 | free-free Euler-Bernoulli f1=1.028(h/L^2)sqrt(E/rho); first-order; Padauk E=12.6GPa rho=745kg/m3 | Padauk | 2.19 | 6.86 | solved L from target_hz |
| C6 | 1046.50 | 11.797 | 1.500 | 0.875 | 2.643 | 9.154 | 1046.50 | free-free Euler-Bernoulli f1=1.028(h/L^2)sqrt(E/rho); first-order; Padauk E=12.6GPa rho=745kg/m3 | Padauk | 2.00 | 6.67 | solved L from target_hz |
| C#6 | 1108.73 | 11.461 | 1.500 | 0.875 | 2.567 | 8.894 | 1108.73 | free-free Euler-Bernoulli f1=1.028(h/L^2)sqrt(E/rho); first-order; Padauk E=12.6GPa rho=745kg/m3 | Padauk | 1.81 | 6.48 | solved L from target_hz |
| D6 | 1174.66 | 11.135 | 1.500 | 0.875 | 2.494 | 8.641 | 1174.66 | free-free Euler-Bernoulli f1=1.028(h/L^2)sqrt(E/rho); first-order; Padauk E=12.6GPa rho=745kg/m3 | Padauk | 1.64 | 6.29 | solved L from target_hz |
| D#6 | 1244.51 | 10.818 | 1.500 | 0.875 | 2.423 | 8.395 | 1244.51 | free-free Euler-Bernoulli f1=1.028(h/L^2)sqrt(E/rho); first-order; Padauk E=12.6GPa rho=745kg/m3 | Padauk | 1.48 | 6.11 | solved L from target_hz |
| E6 | 1318.51 | 10.510 | 1.500 | 0.875 | 2.354 | 8.156 | 1318.51 | free-free Euler-Bernoulli f1=1.028(h/L^2)sqrt(E/rho); first-order; Padauk E=12.6GPa rho=745kg/m3 | Padauk | 1.33 | 5.94 | solved L from target_hz |
| F6 | 1396.91 | 10.211 | 1.500 | 0.875 | 2.287 | 7.923 | 1396.91 | free-free Euler-Bernoulli f1=1.028(h/L^2)sqrt(E/rho); first-order; Padauk E=12.6GPa rho=745kg/m3 | Padauk | 1.19 | 5.77 | solved L from target_hz |
| F#6 | 1479.98 | 9.920 | 1.500 | 0.875 | 2.222 | 7.698 | 1479.98 | free-free Euler-Bernoulli f1=1.028(h/L^2)sqrt(E/rho); first-order; Padauk E=12.6GPa rho=745kg/m3 | Padauk | 1.05 | 5.61 | solved L from target_hz |
| G6 | 1567.98 | 9.638 | 1.500 | 0.875 | 2.159 | 7.479 | 1567.98 | free-free Euler-Bernoulli f1=1.028(h/L^2)sqrt(E/rho); first-order; Padauk E=12.6GPa rho=745kg/m3 | Padauk | 0.92 | 5.45 | solved L from target_hz |
| G#6 | 1661.22 | 9.363 | 1.500 | 0.875 | 2.097 | 7.266 | 1661.22 | free-free Euler-Bernoulli f1=1.028(h/L^2)sqrt(E/rho); first-order; Padauk E=12.6GPa rho=745kg/m3 | Padauk | 0.80 | 5.29 | solved L from target_hz |
| A6 | 1760.00 | 9.097 | 1.500 | 0.875 | 2.038 | 7.059 | 1760.00 | free-free Euler-Bernoulli f1=1.028(h/L^2)sqrt(E/rho); first-order; Padauk E=12.6GPa rho=745kg/m3 | Padauk | 0.69 | 5.14 | solved L from target_hz |
| A#6 | 1864.66 | 8.838 | 1.500 | 0.875 | 1.980 | 6.858 | 1864.66 | free-free Euler-Bernoulli f1=1.028(h/L^2)sqrt(E/rho); first-order; Padauk E=12.6GPa rho=745kg/m3 | Padauk | 0.58 | 5.00 | solved L from target_hz |
| B6 | 1975.53 | 8.586 | 1.500 | 0.875 | 1.923 | 6.663 | 1975.53 | free-free Euler-Bernoulli f1=1.028(h/L^2)sqrt(E/rho); first-order; Padauk E=12.6GPa rho=745kg/m3 | Padauk | 0.48 | 4.85 | solved L from target_hz |
| C7 | 2093.00 | 8.342 | 1.500 | 0.875 | 1.869 | 6.473 | 2093.00 | free-free Euler-Bernoulli f1=1.028(h/L^2)sqrt(E/rho); first-order; Padauk E=12.6GPa rho=745kg/m3 | Padauk | 0.38 | 4.71 | solved L from target_hz |

_Speaker notes:_ Sizes scale via the master scale factor; tuning targets are first-order Helmholtz/cantilever predictions to be empirically corrected per prototype.

---

# Build Workflow
- Design and assumptions
- Source materials and hardware
- Prepare stock, fixtures, and CNC/laser/lathe setup
- Assemble, tune, finish, and validate

---

# Sourcing And BOM
- BOM gives part categories and drawing references.
- Sourcing tracks search terms, supplier candidates, price/date, lead time, substitutions.
- Visual BOM brief turns the parts list into a presentation-ready image board.

---

# Shop Packet
- Cut list for lumber/sheet/blank planning.
- Assembly manual for away-from-keyboard work.
- Validation sheet for measured dimensions, tuning, pass/fail checks.

---

# Drawings, CAD, CNC
- drawing-brief.md defines required views, dimensions, datums, sketch intent.
- cad/ holds models and design tables.
- cnc/ holds CAM, toolpaths, setup sheets, dry-run notes.
- drawings/ holds PDFs, SVGs, DXFs, drawing exports.



---

# Images And Screenshots
- images/xylophone-hero-placeholder.svg



---

# Validation Plan
- A4 = 440 Hz reference check.
- Tuning targets logged in validation.csv.
- Critical dimensions verified against design sheet and CAD.
- Photos and revision notes after each major step.

---

# Open Risks / Decisions
- TBDs in design sheet and BOM.
- Supplier price/availability not yet verified.
- Generated images marked as concept placeholders.
- Empirical corrections await measured prototype data.

---

# Next Actions
- Replace TBDs with measured/source-backed values.
- Verify live supplier price and availability before buying.
- Export final drawings and visual BOM images.
- Regenerate this deck and print packet after final edits.

---

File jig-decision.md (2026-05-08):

# Xylophone — Jig Decisions

Three jig decisions, each with build/no-build recommendation, the
break-even calculation that drives it, and a one-paragraph build
sketch when the answer is build.

## 1. Node-hole drilling jig — **BUILD**

**Decision.** Build a fixed-fence drilling jig with two adjustable
stops keyed to the 22.4% / 77.6% positions of the bar length.

**Rationale.** 25 bars × 2 holes = 50 holes. Each hole must land
within ±1/32" of the node position or the bar's first mode picks up
audible damping. Hand-marking 50 holes from a tape measure is
unreliable at this tolerance. A jig with two flip-stops set against
the bar end pays back the build time on bar #4 or #5.

**Sketch.** Plywood base 22"×6"×1/2", drill press fence along the
back edge, two T-track flip-stops in a pair of 6" T-tracks routed
flush. Each bar's two stop positions get pre-marked on a strip
sticker per note — operator slides the bar against the front stop
for the low-side hole, drills, flips the front stop down and the
back stop up, drills the high-side hole. The stops are positioned
from the bar's actual length, not a percent, so the operator never
does math at the drill press.

## 2. Bar-end-shaving sled — **BUILD**

**Decision.** Build a low-angle hand-plane shooting sled sized to
the longest bar.

**Rationale.** Tuning happens by removing material from the bar
ends — *not* the underside (xylophone has no arch). End-shaving
needs to be square to the bar's long axis and parallel to the
opposite end, otherwise the bar develops a wedge that affects both
the fundamental tuning and the cord-hole alignment. A shooting sled
makes both square and parallel automatic.

**Sketch.** Hardwood base 20"×6", 90° fence along one long edge,
a stop block at the right end and a clamp wedge at the left. The
bar slides against the fence; the plane runs along the base; the
stop block prevents over-running the cut. A piece of 220 paper
glued to the fence prevents skating. Build the fence dead-square
to the base — measure with a machinist square before glue-up.

## 3. Frame-rail miter sled — **NO BUILD; use existing miter saw**

**Decision.** Cut the rail-to-leg miters on the existing sliding
compound miter saw. No jig.

**Rationale.** Eight 45° miters total (four leg ends × two each).
A standard miter saw with a sharp 80T blade lands every miter at
±0.25° easily, and the joints are reinforced by gusset plates
anyway. Building a miter sled would cost a half-day and pay back
nothing for an 8-cut job.

**Note for marimba sister repo.** A multi-octave marimba has 60+
miter cuts in the resonator-tube wells alone. The marimba repo
should re-evaluate this decision and likely build a dedicated
sled.

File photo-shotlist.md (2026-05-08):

# Xylophone — Photo Shotlist

Ten shots that the build-log site, capstone deck, and visual BOM all
draw from. Tied to the repo-level `docs/photo-pipeline.md` rules
(neutral background, 5500K key light, sensor at instrument plane,
no flash, JPEG + RAW). When a photo is captured, drop it under
`images/` with the slug filename listed below — the deck and site
templates will pick them up.

## 1. Hero — `images/01-hero.jpg`

Full instrument on a clean dark-grey background, three-quarter angle
from above-right, both mallets resting at the keyboard end of the
frame. Lens normal-to-wide (35–50mm full frame). This is the README
hero swap — until captured, `images/xylophone-hero-placeholder.svg`
stands in.

## 2. Bar fan — `images/02-bar-fan.jpg`

All 25 bars laid out flat on a white seamless, shortest-to-longest,
1/2" gap between each. Top-down. This image goes on the deck's
"Family Plan" slide.

## 3. Node-hole detail — `images/03-node-hole-detail.jpg`

Macro of the 1/8" node hole on the C5 bar with paracord threaded
through. Lens 100mm macro. Light raking from one side to bring out
the cord texture and the hole chamfer. Goes on the assembly-manual's
node-suspension step.

## 4. Frame elevation — `images/04-frame-elevation.jpg`

Side-on, eye-level, frame only (no bars), centered. Shot far enough
back to be free of perspective distortion (~85mm full frame).
Used in `drawing-brief.md` as the dimension reference photo.

## 5. Mallet trio — `images/05-mallet-trio.jpg`

Hard rubber, lexan, and rosewood-head mallets laid parallel on a
white seamless, heads aligned at the top. Top-down. Used in the
`bom.csv`-driven visual BOM.

## 6. Suspension cord — `images/06-suspension-cord.jpg`

Three-quarter view of one full bar suspended on the cord at both
node holes, with the cord ends terminating at the rail with the brass
finish washers. Shows the geometry without the rest of the bars in
frame. Used on the build-log site's "How the bars are suspended"
section.

## 7. Tuner on bar — `images/07-tuner-on-bar.jpg`

The Korg OT-120 displayed mid-measurement on the A5 bar, mallet just
having struck. Captures the validation workflow in one frame. Used
on the validation slide of the deck.

## 8. Resonator stub — `images/08-resonator-stub.jpg` (deferred)

A single quarter-wave aluminum tube cut to the C5 resonator length
(5.22"), held against the underside of the suspended C5 bar. Shot
when v2 build adds resonators. Until then, this slot stays blank.

## 9. Moisture meter — `images/09-moisture-meter.jpg`

Pin meter inserted into the end-grain of a Padauk blank pre-glue-up,
display showing 6.5–7.5% MC. Goes on the assembly-manual's
"Verify moisture" step.

## 10. Finished assembly — `images/10-finished-assembly.jpg`

Three-quarter wide-angle of the finished xylophone in a play-ready
position (mallets in player's hands, bars attached, frame on a
real floor). Eye-level standing. The "this thing works" portrait
that closes the build-log site.

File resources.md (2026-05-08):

# Xylophone — Resources

Citations, references, and the source-of-truth pointers that this
packet relies on. Where the packet states a number, this file says
*where the number came from*.

## Acoustic physics

- **Fletcher, Neville H., and Thomas D. Rossing.** *The Physics of
  Musical Instruments,* 2nd ed., Springer, 1998. Chapter 19 (Bars,
  Plates, and Membranes) — the canonical free-free Euler-Bernoulli
  derivation. Equations 19.7–19.13 yield the `K_free_free / K_cantilever
  = (4.730/1.875)² ≈ 6.36` factor used throughout this packet.
- **Bork, Ingolf.** "Practical Tuning of Xylophone Bars and Resonators,"
  *Applied Acoustics* 46 (1995): 103–127. Source for the 12th-overtone
  tuning convention and the bar-end-shaving correction shape. Bork's
  measured-vs-flat-bar second-mode ratio (~2.756) is the basis for the
  `first-mode-vs-second-mode-misalignment` risk.
- **Suits, B. H.** "Basic Physics of Xylophone and Marimba Bars."
  *American Journal of Physics* 69(7) (2001): 743–750. Clean
  derivation of the arch-undercut math the marimba sister repo will
  inherit; **explicitly cited** here as the "deferred-to-marimba"
  reference.
- **`acoustic-models.md`** (instrument-maker-v4 skill,
  `references/acoustic-models.md`). Free-Free Beams section is the
  primary citation — it both consolidates the formula in Tony's house
  units (h, L, E, ρ) and carries the empirical-correction guard rules
  that govern when K-constants do and do not apply.

## Material constants

- **Wood Database** (Eric Meier, https://www.wood-database.com/). E
  and ρ values for African Padauk (E ≈ 12.6 GPa, ρ ≈ 745 kg/m³),
  Honduras Rosewood (E ≈ 14.1 GPa, ρ ≈ 1000 kg/m³), and Hard Maple
  (E ≈ 12.6 GPa, ρ ≈ 705 kg/m³). Cross-checked against the K-constant
  table in `acoustic-models.md`.

## Tuning workflow / measurement

- **`record_measurement.py`** (instrument-maker-v4 skill,
  `scripts/record_measurement.py`). Schema for `validation.csv` and
  the per-family corrections database. The `tuner_make_model`,
  `temp_F`, `humidity_RH_percent`, and `cents_target` columns in
  this packet's `validation.csv` map 1:1 to the script's CLI flags.
- **Korg OT-120** orchestral chromatic tuner. ±0.1 cent accuracy in
  the C5–C7 range. Listed as the device of record in `bom.csv`.

## Empirical-correction guard rules

- **`acoustic-models.md`** "Empirical-correction guard rules" section.
  Cited in `design.md`'s Governing Model and in every prediction line
  of `family-spec.csv`. The summary in shop-friendly terms: K2 and
  end-corrections **do not apply** to bar idiophones; cantilever
  K-constants apply to free-free via the 6.36× factor; everything is
  *first-order* until measured.

## Repository conventions

- **`tongue-drum/README.md`** (sister repo). README structure,
  cross-repo link block, magazine-baseline attribution pattern. This
  packet's `README.md` rewrites in the same shape.
- **`tongue-drum/cad/`** (sister repo). SolidWorks master-layout
  convention for parametric design tables. Cited in `cad/README.md`
  as the model the xylophone CAD will follow when built.
- **`golden-examples.md`** (instrument-maker-v4 skill,
  `references/golden-examples.md`). Mode A root-mode layout exemplar
  — every file in this packet sits at the repo root because that
  reference says so.

## Marimba/xylophone difference summary

The single best one-page summary of how xylophone and marimba differ:
**Suits 2001** (above). The salient points the packet operationalizes:

- Xylophone tunes the second mode to a 12th (3:1 ratio) above the
  fundamental; marimba tunes to two octaves (4:1).
- Xylophone bars are typically rosewood or padauk, smaller cross-section,
  often without arch undercut in low-end / educational instruments.
- Xylophone resonators (when present) are shorter quarter-wave tubes;
  marimba resonators are tuned at the bench by ear.
- Mallets are harder for xylophone; bars consequently must be harder
  wood and well-supported at the nodes.

Every "marimba-equivalent" callout in `design.md` traces back to this
section.

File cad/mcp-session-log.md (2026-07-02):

# CAD MCP Session Log

Status: stub for V5 provenance.

No MCP, SolidWorks, Illustrator, Blender, OpenSCAD, or measurement tooling was
available in this Round 2 lane. No CAD geometry, DXF coordinates, measured
tuning frequencies, renders, or fabrication drawings were created.

| session_id | tool | input_authority | outputs | role | authority_result | review_status | notes |
| --- | --- | --- | --- | --- | --- | --- | --- |
| 2026-05-29-gpt55-xylophone-r2 | none | existing packet docs only | `drawings/per-bar-dxf-authority-register.csv`; `v5-tier1-authority-gates.csv` | authority_scaffold | pending_measurement | unreviewed | Text-only scaffold. Future CAD/DXF work must create a new session row with the actual tool and generated outputs. |
| fable-v5-refresh-2026-07-01 | claude-code (Fable 5) + OpenSCAD CLI | family-spec.csv, cut-list.csv (RAIL-L/R, LEG-*), design.md "Frame Layout" | cad/xylophone.scad | cad_authoring | pending_measurement | self_checked | Parametric bar-length-schedule + trestle-frame envelope for all 25 bars. Bar arch/tuning geometry and resonator tubes out of scope. OpenSCAD render check: pass (openscad -o STL, exit 0). |
| fable-v5-refresh-2026-07-01 | claude-code (Fable 5) | xylophone-design-table.xlsx, family-spec.csv, xylophone-starter.wl | visual-output-register.csv | packet_refresh | fabrication | self_checked | V5 refresh pass: provenance rows added for xylophone-design-table.xlsx and family-spec.csv (satisfies V5 fabrication-artifact logging); register row added for the pre-existing xylophone-starter.wl (was unregistered). No dimension changes made to existing tabular packet data. |

## Next Provenance Requirement

Before any SolidWorks or DXF artifact is cited as V5 authority, add a new row
with the real tool session, source inputs, generated files, review status, and
whether the output is fabrication authority, derived preview, concept only, or
still pending measurement.

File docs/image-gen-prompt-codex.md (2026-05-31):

# Xylophone Image-Gen Prompts

Concept visualization only; not fabrication authority. Do not infer bar
lengths, node-hole positions, resonator lengths, or frame joinery from these
prompts.

## Hero Prompt

Photorealistic 3/4 product photograph of a finished compact 25-bar chromatic xylophone, C5 to C7 concept, with African Padauk flat rectangular bars arranged in two chromatic rows on a hard-maple trestle frame. Show paracord-style suspension passing through node holes, Baltic-birch corner gussets, a clean 21-inch-class tabletop frame proportion, and hard rubber mallets laid beside the instrument for scale. The bars should be reddish-orange Padauk with satin finish, no arch undercuts, no mandatory resonator tubes, and a crisp educational/prototype build aesthetic. Clean studio background, soft directional lighting, 50mm lens, high detail, photorealistic.

## In-Context Prompt

Photorealistic workshop-performance scene of the compact xylophone on a sturdy bench or low stand while a player uses hard rubber mallets. Include a tuner, pilot bar offcut, small drill jig, and neatly organized bars in the background to suggest the measured-tuning workflow. Natural shop light, warm wood tones, realistic mallet grip, clear chromatic bar layout without printed note names.

## Detail / Macro Prompt

Photorealistic macro close-up of several Padauk xylophone bars on cord suspension: flat-bottom rectangular bars, smooth rounded edges, clean node holes with cord passing through, and a hard-maple rail below. Emphasize wood grain, slight color variation between bars, precise spacing, and the tactile contact surface where hard mallets strike. High-detail macro, shallow depth of field.

## Negative / Avoid

No text, logos, watermarks, marimba arch undercuts, oversized resonator forest, fake note labels, impossible cord paths, extra hands, or distorted mallets.

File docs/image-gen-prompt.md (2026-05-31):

# Image-Gen Prompts

Concept image only; not fabrication authority. Do not include cut-ready dimensions, hole locations, or toolpaths.

## Hero Prompt

A finished concert-style chromatic xylophone photographed as a real physical object: a graduated fan of 25 rectangular flat-bottom hardwood bars in warm reddish-orange African Padauk, descending smoothly from the longest bar on the left to the shortest on the right, every bar the same constant width and thickness so the eye reads a clean tapering wedge of identical-section blanks. The bars rest on a light-toned hard-maple trestle frame — two parallel suspension rails carried on four square legs at standing-play height — and each bar is suspended on thin black 1/8-inch paracord threaded through small holes near the two vibration nodes, so the bars float a hair above the rails rather than touching them. Soft round-over on every long bar edge catches the light. Two hard-rubber mallets with slender shafts rest across the keyboard end. Clean neutral mid-grey studio background, soft directional studio light, three-quarter product-photography angle from slightly above the right, ~50mm lens, shallow but coherent focus, high detail, photorealistic, no text labels, no measurement callouts.

## In-Context Prompt

The same Padauk-and-maple chromatic xylophone staged in a bright woodworking shop, frame standing on a real plank floor, a player's two hands holding hard-rubber mallets mid-strike over the lower bars, warm natural window light raking across the orange-red bar fan and pale maple frame. Shavings and a hand plane sit softly out of focus on a bench behind. Shallow depth of field isolating the struck bar, environmental storytelling of a one-session shop build, concept visualization only, photorealistic, no text, no dimension annotations.

## Detail Prompt

Macro close-up of a single suspended Padauk bar at one of its node holes: a small drilled hole near the bar end with thin black paracord passing cleanly through it, the bar floating just clear of the pale maple suspension rail, the chamfered hole edge and the fine grain and quartersawn figure of the reddish-orange wood crisp under hard raking sidelight. Tight focus on the cord-through-hole suspension geometry and the rounded-over bar edge, blurred neighboring bars receding behind. High detail, photorealistic, no measurements, no text.

## Negative / Avoid

No text, logos, watermarks, or fake maker marks; no dimension lines, callouts, or rulers; no parabolic arch undercut on the bar undersides (these are flat-bottom bars); no metal resonator tubes under the bars; no impossible suspension; anatomically plausible hands if a player is shown.

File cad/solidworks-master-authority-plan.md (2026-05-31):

# Xylophone SolidWorks Master Authority Plan

Current status: `authority_plan_only`.

No SolidWorks master part, assembly, drawing package, DXF export, or extracted
dimension CSV exists in this repo yet. This document defines the gate for that
future work; it is not CAD authority by itself.

## Authority Chain

The current dimensional authority remains:

1. `xylophone-design-table.xlsx`
2. `family-spec.csv`

Those files are first-order planning authority only. They are not bench
validated and do not make the packet build-ready. The SolidWorks master may be
promoted only after it is proven to reproduce those table values and the pilot
bar measurement loop has closed enough to justify per-bar drawing release.

## Required Master Files

When built, the CAD set should follow the existing idiophone convention:

| Planned file | Required status before release |
| --- | --- |
| `cad/XYL-001_MasterLayout.SLDPRT` | Design-table driven master part with one bar configuration per `family-spec.csv` note. |
| `cad/XYL-001_Xylophone.SLDASM` | Assembly referencing the master layout plus non-authoritative frame context. |
| `cad/Extract_Xylophone_Dimensions_AllConfigs.bas` | Macro that exports every configuration to a CSV dimension report. |
| `cad/XYL-001_dimensions.csv` | Extracted dimensions compared back to `family-spec.csv` before any DXF release. |

Do not add these files as fabrication authority until the review rows below are
complete and `visual-output-register.csv` has been updated with the released
CAD/DXF artifacts.

## Master Parameters

Each bar configuration must expose these values as global variables or
design-table columns:

| Parameter | Source | Review rule |
| --- | --- | --- |
| `note` | `family-spec.csv` | Configuration name and title block must match. |
| `target_hz` | `family-spec.csv` | Reference only; not a dimension. |
| `bar_length_in` | `family-spec.csv` | Must match extracted CAD dimension within 0.001 in before release. |
| `bar_width_in` | `family-spec.csv` | Must match extracted CAD dimension within 0.001 in before release. |
| `bar_thickness_in` | `family-spec.csv` | Must match extracted CAD dimension within 0.001 in before release. |
| `hole_pos_low_in` | `family-spec.csv` | Must match extracted CAD dimension within 0.001 in before release. |
| `hole_pos_high_in` | `family-spec.csv` | Must match extracted CAD dimension within 0.001 in before release. |
| `node_hole_dia_in` | `drawing-brief.md` | `0.125 in`; confirm against the selected suspension cord before release. |
| `edge_roundover_in` | `drawing-brief.md` | `0.0625 in`; review after pilot-bar machining. |

## Release Gates

- Cut and measure the A5 pilot bar through `validation.csv` rows V2 and V3.
- Decide whether the first measured correction changes the family table before
  per-bar DXF export.
- Build the SolidWorks master from the table, then export all configuration
  dimensions to CSV.
- Compare extracted CAD dimensions against `family-spec.csv`; resolve every
  mismatch before release.
- Generate per-bar DXF drawings only after the comparison passes.
- Complete `drawings/per-bar-dxf-checklist.csv` for all 25 bars.
- Update `visual-output-register.csv` with any released CAD/DXF artifacts and
  keep previews marked `derived_preview`.

## Explicit Non-Claims

- This plan does not create measured bar evidence.
- This plan does not release per-bar DXF files.
- This plan does not authorize CNC, laser, bandsaw, drill, or router toolpaths.
- This plan does not promote the packet past `L1_packet -> measurement_required`.
- Preview images and SVGs remain non-authoritative unless their source CAD,
  DXF, or design-table record is named in the visual authority register.

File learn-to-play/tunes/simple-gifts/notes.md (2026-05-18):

# Notes: Simple Gifts

**Provenance:** Written by Shaker Elder Joseph Brackett, Alfred Shaker Community, Maine, 1848.
Published in the Shaker tradition as a public-domain hymn. Copland's "Appalachian Spring" (1944)
arrangement is NOT PD — use only the Brackett lead-sheet melody, arranged fresh here.

**Range check:** F4–D5. Sits in the heart of the xylophone's range.

**Practice tips:**
1. The tied final note (f8-) should sustain fully — let the resonator bloom.
2. The ascending 4th (F to Bb) in bar 3 is characteristic — don't skip over it.
3. Play with a singing, legato mallet style — oppose the usual staccato xylophone approach.

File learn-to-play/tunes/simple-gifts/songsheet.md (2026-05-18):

# Simple Gifts — Songsheet

**Key:** F major  **Tempo:** ♩= 100  **Meter:** 4/4  **Difficulty:** ★★☆
**Range:** F4–D5  **Source:** Elder Joseph Brackett, Shaker hymn (1848), PD

## Music
```
X:3 T:Simple Gifts M:4/4 L:1/8 Q:1/4=100 K:F
f4 f2 g2 | a4 f4 | a4 b2 c'2 | d'8 |
d'2 c'2 a2 c'2 | d'4 f4 | c'4 a2 f2 | g8 |
a4 a2 g2 | f4 d'4 | c'2 a2 c'2 a2 | f8 |
f4 g2 a2 | g4 e4 | f8- | f8 |
```
*(In K:F, b = Bb automatically)*

## Notes
- "Simple Gifts" has a smooth, flowing character — connect each note.
- The Bb (written as b in K:F) is the only non-C-major note.
- This was Aaron Copland's source for the "Appalachian Spring" variations (1944) — his
  arrangement is copyrighted, but Brackett's original melody is PD.

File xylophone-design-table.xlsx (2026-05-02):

Xylophone — CNC Bar Design Table
Free-Free Beam (no arch) · f = K × t / L² · 3rd Harmonic Tuning · λ₁ = 4.730
DESIGN INPUTS
Material | Padauk | ← Match to Marimba material library
K Constant (free-free) | 155502 | ← From Marimba sheet or = 6.36 × Tongue Drum K
Bar Thickness (in) | 0.750 | ← 3/4" concert, 5/8" student
Resonator Bore (in) | 1.250 | ← PVC Schedule 20 ID
BAR SCHEDULE — 44 Chromatic Bars (F4–C8)
# | Note | MIDI | Freq (Hz) | Bar Length (in) | Bar Length (mm) | Bar Width (in) | Node 1 (in) | Node 2 (in) | Res. Tube (in) | Res. Tube (mm) | BUILD SPECIFICATIONS
1 | F4 | 65 |  |  |  |  |  |  |  |  |  | Concert (3.5 oct) | Student (2.5 oct)
2 | F#4 | 66 |  |  |  |  |  |  |  |  | Range | F4–C8 (44 bars) | F4–C7 (32 bars)
3 | G4 | 67 |  |  |  |  |  |  |  |  | Bar Material | Rosewood / Padauk | Padauk / Hard Maple
4 | G#4 | 68 |  |  |  |  |  |  |  |  | Bar Thickness | 3/4" (0.750") | 5/8" (0.625")
5 | A4 | 69 |  |  |  |  |  |  |  |  | Bar Width Range | 1.0"–1.5" | 1.0"–1.375"
6 | A#4 | 70 |  |  |  |  |  |  |  |  | Resonator Material | 1-1/4" PVC Sch 20 | 1" PVC Sch 20
7 | B4 | 71 |  |  |  |  |  |  |  |  | Resonators | 37 tubes (F4–C7) | 32 tubes (all)
8 | C5 | 72 |  |  |  |  |  |  |  |  | Frame Size | 48" × 24" × 30"h | 36" × 20" × 28"h
9 | C#5 | 73 |  |  |  |  |  |  |  |  | Rail Material | Maple or aluminum | Pine or maple
10 | D5 | 74 |  |  |  |  |  |  |  |  | String Material | Paracord through nodes | Paracord through nodes
11 | D#5 | 75 |  |  |  |  |  |  |  |  | Mallets | Hard rubber / plastic | Hard rubber
12 | E5 | 76 |  |  |  |  |  |  |  |  | CNC Operations | Bars only (no arch) | Bars only
13 | F5 | 77 |  |  |  |  |  |  |  |  | Total Weight (est.) | ~35 lbs | ~20 lbs
14 | F#5 | 78
15 | G5 | 79
16 | G#5 | 80
17 | A5 | 81
18 | A#5 | 82
19 | B5 | 83
20 | C6 | 84
21 | C#6 | 85
22 | D6 | 86
23 | D#6 | 87
24 | E6 | 88
25 | F6 | 89
26 | F#6 | 90
27 | G6 | 91
28 | G#6 | 92
29 | A6 | 93
30 | A#6 | 94
31 | B6 | 95
32 | C7 | 96
33 | C#7 | 97
34 | D7 | 98
35 | D#7 | 99
36 | E7 | 100
37 | F7 | 101
38 | F#7 | 102
39 | G7 | 103
40 | G#7 | 104
41 | A7 | 105
42 | A#7 | 106
43 | B7 | 107
44 | C8 | 108
WOLFRAM EXPLORATIONS — XYLOPHONE
Roadmap-inspired notebook ideas mapped to this instrument.
Sound synthesis
→ The Complete Tongue Drum / Xylophone Spectrum (roadmap: Publication)
AudioGenerator: synthesize bars C5–C8 with hard-mallet attack + free-free overtone series (1, 2.76, 5.40, 8.93). Compare wood vs metal vs plastic: rosewood, padauk, aluminum, fiberglass — same length, hear K_material in real time.
ListLinePlot energy decay envelopes for each material — bright + short (steel) vs warm + long (rosewood).
Computational physics
→ Cantilever / Free-Free Mode Shapes (roadmap: NDSolve)
NDEigensystem on Euler-Bernoulli beam with free-free BCs; animate first 5 modes. Show why xylophone overtones are inharmonic (2.76·f1, 5.40·f1, 8.93·f1) and contrast with marimba's 4·f1 arch tuning.
Wood-grain rotation effect: rotate the bar's E_parallel direction by θ = 0–90° → plot f vs θ. Quantify how much detuning a misaligned grain blank introduces.
Wolfram functions: NDEigensystem free-free beam; Periodogram for 3:1 partial verification; FindPeaks for inharmonicity quantification.
Engineering & tolerance
→ Tolerance Stack-Up + Sensitivity Ranking (roadmap: Engineering)
Monte Carlo: NormalDistribution[L,σ_L] + NormalDistribution[t,σ_t] → frequency error histogram. Find which dim (L vs t vs ρ) drives most variance — ∂f/∂L vs ∂f/∂t ranking.
Material Pareto: NMinimize over {min mass, max Q, hit ±5 cents}; compare rosewood vs padauk vs synthetic phenolic.
Node positions: 22.4% and 77.6% from each end — drill cord holes here.
Manufacturing
→ G-Code Toolpath Animator + Stave Yield Optimizer (roadmap: Manufacturing)
Parse the bar-cutting .nc file; animate bit motion in 3D; flag rapid-into-stock errors before the cut.
2D nesting on 4x8 hardwood blank: arrange 44 bars (lengths 6"–16") to minimize offcut. RegionNearest + simulated annealing.
§5 — Executable Cells
kXylo[E_,ρ_]:=(4.730^2/(2 π)) Sqrt[E/(12 ρ)] / 0.0254
fBar[t_,L_,K_]:=K t/L^2
lBar[f_,t_,K_]:=Sqrt[K t/f]
f2Ratio := f2 / f1 (* target ~3 for xylophone, ~4 for marimba *)
§6 — Wolfram Functions
NDEigensystem, Manipulate, Animate, Periodogram, FindPeaks, SemanticImport, CloudDeploy, FormFunction.

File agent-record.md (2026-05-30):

# Agent Record

Round: 2 idiophone recovery
Date: 2026-05-29
Lane: gpt-5.5 `isla-xylophone-6`
Branch: `gpt55/xylophone-r2`
Issue: #6

## Contract

- Network blocked: no `gh`, no `git push`.
- Local branch and local commit only.
- No fabricated CAD geometry, DXF coordinates, measured partials, or tuning frequencies.
- Add SolidWorks and per-bar DXF authority structure with pending/concept authority only.

## qmd Step 0

Commands run from this repo:

- `timeout 20 qmd query "xylophone tuning packet"`
  - Crashed in Bun/node-llama-cpp after GPU fallback and rerank startup.
  - No authoritative result was used from the query path.
- `timeout 20 qmd search "xylophone" -c instrument-builds`
  - Found `qmd://instrument-builds/skills/v4/instrument-maker-v4/references/solidworks-templates/xylophone.md`.
  - Found `qmd://instrument-builds/skills/v4/instrument-maker-v4/references/solidworks-templates/readme.md`.
  - Found `qmd://instrument-builds/docs/openscad-sources/readme.md`.
  - Found an older acoustic-model reference noting xylophone as a free-free beam idiophone.

## Work Completed

- Added `drawings/per-bar-dxf-authority-register.csv` with one pending row per bar.
- Added `v5-tier1-authority-gates.csv` for SolidWorks, extracted dimensions, DXF release, visual register, and measurement gates.
- Added `cad/mcp-session-log.md` as an explicit no-tool/no-output provenance stub.

## Honesty Boundary

This lane does not create CAD, DXF, measured tuning data, per-bar coordinates,
or shop-release geometry. The per-bar register names intended configurations
and future output paths only; all authority stays `pending_measurement`.

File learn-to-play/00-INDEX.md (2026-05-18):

# Xylophone — Starter Songbook

The xylophone has wooden bars that produce a drier, more percussive tone than the glockenspiel.
Its resonators amplify each bar's natural pitch. It speaks quickly — ideal for dancing rhythms.

## Instrument range
- Beginner range used here: **F4–F6** (f to f'' in ABC notation)
- Full concert xylophone: F4–C8; soprano xylophones start at C5

## Difficulty key
- ★☆☆ — Beginner: stepwise, short range, simple rhythms
- ★★☆ — Intermediate: thirds and fifths, syncopation
- ★★★ — Advanced: runs, wide leaps, varied rhythms

## Tunes in this songbook
1. `tunes/mary-had-a-little-lamb/` ★☆☆ — Classic beginner melody (E major)
2. `tunes/when-the-saints/` ★☆☆ — When the Saints Go Marching In (C major)
3. `tunes/simple-gifts/` ★★☆ — Simple Gifts, Shaker hymn (F major)
4. `tunes/old-joe-clark/` ★★☆ — Old Joe Clark, Appalachian fiddle tune (A mixolydian)
5. `tunes/shady-grove/` ★★★ — Shady Grove, Appalachian ballad (D dorian)

## Mallet guidance
- Use medium-hard rubber mallets — softer mallets lose definition on wood bars.
- Xylophone resonates faster than glockenspiel; mallet rebound is critical.
- For dampening (staccato), briefly touch the bar edge after striking.

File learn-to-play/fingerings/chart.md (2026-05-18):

# Xylophone Bar Layout Reference

Standard layout (bass F4 on left, ascending to right):

```
   ┌─────┐ ┌─────┐   ┌─────┐ ┌─────┐ ┌─────┐
   │ Gb4 │ │ Ab4 │   │ Bb4 │ │ Db5 │ │ Eb5 │   ← Upper row
   └─────┘ └─────┘   └─────┘ └─────┘ └─────┘
 ┌───┐ ┌───┐ ┌───┐ ┌───┐ ┌───┐ ┌───┐ ┌───┐ ┌───┐
 │ F4│ │ G4│ │ A4│ │ Bb4│ │ C5│ │ D5│ │ E5│ │ F5│  ← Lower row
 └───┘ └───┘ └───┘ └───┘ └───┘ └───┘ └───┘ └───┘

Tunes in this songbook use: A4  C5  D5  E5  F5  G5  A5
(plus Bb4 for Simple Gifts, G#4 for Old Joe Clark is natural G4)
```

## Mallet technique
- Hard rubber or plastic mallets — wooden mallets create a softer, more muted tone.
- Strike near center; resonators extend below each bar.
- Xylophone bars are thicker than glockenspiel — a firmer stroke is needed.
- The sound decays quickly (shorter than glockenspiel) — use staccato for clean passages.

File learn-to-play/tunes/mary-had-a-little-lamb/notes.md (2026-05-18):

# Notes: Mary Had a Little Lamb

**Provenance:** Melody is traditional (possibly "Goodnight Ladies" era). Lyrics by Sarah Josepha Hale,
published 1830 in "Poems for Our Children." Both are in the public domain.
This arrangement is freshly written from the melody — no modern arranger rights claimed.

**Range check:** C5–G5. Only 5 distinct pitches — ideal for first-time learners.

**Practice tips:**
1. Four bars, then four bars again (varied). Total: 8 bars.
2. The half-note rests (e'2, d'2) — let the bar ring, don't mute it.
3. At ♩= 96, play evenly. This tune should sound mechanical and steady.

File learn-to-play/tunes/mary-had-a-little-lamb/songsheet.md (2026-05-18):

# Mary Had a Little Lamb — Songsheet

**Key:** C major  **Tempo:** ♩= 96  **Meter:** 4/4  **Difficulty:** ★☆☆
**Range:** C5–G5  **Source:** Trad. melody; Hale lyric 1830, PD

## Music
```
X:1 T:Mary Had a Little Lamb M:4/4 L:1/4 Q:1/4=96 K:C
e' d' c' d' | e' e' e'2 | d' d' d'2 | e' g' g'2 |
e' d' c' d' | e' e' e' e' | d' d' e' d' | c'4 |
```

## Notes
- Uses only 5 notes: C D E G — plus the upper G5. No sharps or flats.
- This is an ideal first tune to test your mallet accuracy on each bar.
- The descending E-D-C motion (bar 1) is the signature gesture — isolate it first.

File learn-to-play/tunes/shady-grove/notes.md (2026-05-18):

# Notes: Shady Grove

**Provenance:** Traditional Appalachian ballad, documented in multiple PD collections
(e.g., Cecil Sharp, 1917). The Crosby, Stills, Nash & Young recording and other modern
arrangements are NOT PD — use only the lead-sheet traditional melody.

**Range check:** A3–A5 (two octaves). The low A may fall below some shorter xylophones.
If needed, transpose up a fourth (starting on D rather than A).

**Practice tips:**
1. The 3/4 waltz feel should be gentle and slightly rubato (flexible tempo).
2. The drop to the low A (bar 8) is dramatic — prepare by lifting the mallet early.
3. This is the most "singing" tune in the collection — connect each note like a vocal phrase.

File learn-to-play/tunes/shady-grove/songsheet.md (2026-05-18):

# Shady Grove — Songsheet

**Key:** D dorian  **Tempo:** ♩= 80  **Meter:** 3/4  **Difficulty:** ★★★
**Range:** A3–A5  **Source:** Traditional Appalachian ballad, public domain

## Music
```
X:5 T:Shady Grove M:3/4 L:1/4 Q:1/4=80 K:Dmin
a' | a' g' e' | d'2 e' | g'2 e' | d'3 |
d' e' g' | a'2 g' | e'2 d' | A3 |
(repeat for verse 2)
```

## Modal note
D dorian = D natural minor with B-natural (not Bb). This gives the tune its archaic, folk character.

## Notes
- The pickup note a' starts the melody; the final bar ties across for a held ending.
- The low A (A3 — capital A in ABC) drops two octaves below the melody.
  If your xylophone doesn't reach A3, substitute A4 (a in ABC).
- Play slowly with feeling — don't rush the spaces between phrases.

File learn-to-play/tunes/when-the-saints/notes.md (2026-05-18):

# Notes: When the Saints Go Marching In

**Provenance:** Traditional African-American spiritual, earliest documented recording 1896.
Published in various PD hymnals before 1925. Melody is in the public domain.
The famous Louis Armstrong recording (1938) is NOT PD — use only the lead-sheet melody.

**Range check:** C5–A5. The A5 appears only once (bar 14, pickup to final phrase).

**Practice tips:**
1. The melody repeats almost exactly — once you know bars 1–8, you know the whole piece.
2. The "march" character comes from strong quarter-note beats — don't swing the eighths.
3. This tune works well as a finale in a percussion ensemble — play it twice through.

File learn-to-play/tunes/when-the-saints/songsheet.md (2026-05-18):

# When the Saints Go Marching In — Songsheet

**Key:** C major  **Tempo:** ♩= 112  **Meter:** 4/4  **Difficulty:** ★☆☆
**Range:** C5–A5  **Source:** Traditional spiritual, public domain

## Music
```
X:2 T:When the Saints Go Marching In M:4/4 L:1/4 Q:1/4=112 K:C
c' e' f' g'2 | c' e' f' g'2 | c' e' f' g' e' | c' e' d'2 |
c' e' f' g'2 | c' e' f' g'2 | c' e' g' e' c' | d'4 |
e'2 e'/ d'/ e' | c' e' g'2 | g' e' g' e'2 | c' d'2 c' |
c' e' f' g'2 | c' e' f' g' a' | g' e' c' d' | c'4 |
```

## Notes
- Upbeat marching feel — keep the quarter notes crisp and even.
- The "chorus" (bars 9–12) leaps up — watch the E-to-G skip.
- Staccato approach (short, separated notes) matches the march character well.

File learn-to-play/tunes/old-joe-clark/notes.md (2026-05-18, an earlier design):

# Notes: Old Joe Clark

**Provenance:** Traditional Appalachian fiddle tune, origin uncertain, documented from the early
19th century. Multiple PD versions in Cecil Sharp's collections. This lead-sheet melody is PD.

**Range check:** D4–F5. Spans nearly two octaves — the B section sits a fifth higher than A.

**Practice tips:**
1. Use hard, crisp mallets for this one — the staccato character suits the wood tone.
2. Practice the repeated-note runs (e2 e2 e2) slowly to build evenness.
3. The key signature is A mixolydian — there's no key signature notation for mixolydian,
   so play G natural (not G#) throughout.

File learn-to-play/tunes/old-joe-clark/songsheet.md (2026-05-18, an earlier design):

# Old Joe Clark — Songsheet

**Key:** A mixolydian (A major with G natural)  **Tempo:** ♩= 132
**Meter:** 4/4  **Difficulty:** ★★☆  **Range:** D4–F5
**Source:** Traditional Appalachian fiddle tune, public domain

## Music
```
X:4 T:Old Joe Clark M:4/4 L:1/8 Q:1/4=132 K:Amix
A2 A2 A2 c2 | B2 G2 E2 G2 | A4 A2 G2 | E8 |
A2 A2 A2 c2 | B2 G2 E4 | G4 E2 D2 | A8 :|
|: e2 e2 e2 f2 | e2 d2 B4 | e2 e2 e2 f2 | e2 d2 B2 G2 |
e2 e2 e2 f2 | e2 d2 B2 A2 | G4 E2 D2 | A8 :|
```

## Modal note
A mixolydian = A major with a lowered 7th degree (G natural instead of G#).
The G-natural gives old-time Appalachian fiddle tunes their characteristic "open" sound.

## Notes
- This is the fastest tune in the songbook — start at ♩= 80 and build up.
- The repeated-note figures (A2 A2 A2) drive the rhythm — keep them even.
- Two sections: A part (A-A-G feel) and B part (higher e-e-e run).

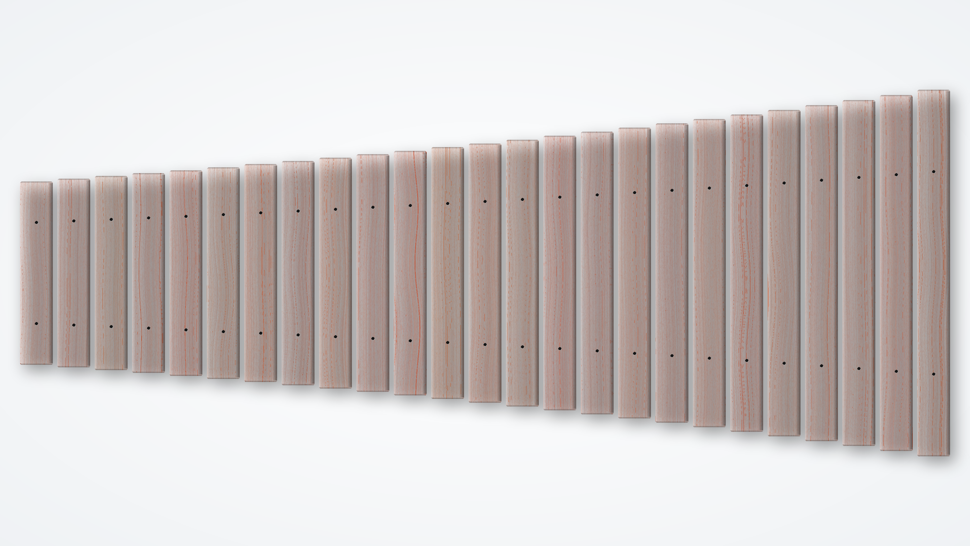
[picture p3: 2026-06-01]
images/family-group.png

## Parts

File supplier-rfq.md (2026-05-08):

# Xylophone — Supplier RFQ

Template — paste into supplier email or web form. The bar-stock RFQ
is the only critical-path RFQ; everything else is COTS from
`sourcing.csv` and does not need a custom quote.

---

**Subject:** Padauk bar-stock quote — 25-bar xylophone build

Hello,

I'm building a 25-bar chromatic xylophone (C5–C7) and I'd like a
quote on Padauk lumber for the bar set. Specs:

- **Species:** African Padauk (*Pterocarpus soyauxii*) — *not*
  Burma Padauk.
- **Form:** 4/4 lumber (15/16" rough, surfaced 4 sides to roughly
  3/4"–7/8" final), or fall-back to S2S if S4S is unavailable.
- **Grain:** **Quartersawn** strongly preferred (radial grain on the
  bar face). Riftsawn acceptable on 25–35% of the order. Flatsawn
  rejected — bars will warp.
- **Moisture content:** **Kiln-dried to 6–8% MC.** Please measure with
  a pin meter at multiple points and confirm in writing.
- **Defect tolerance:** No knots, no shake, no end-checks longer than
  1/2", no insect damage, no sap pockets. Color variation acceptable.
- **Total board feet:** Approximately **15 BF** to yield 25 bars
  (longest 17", shortest 9", at 1.5"×7/8") plus 20% waste.
- **Lengths preferred:** Boards in the 36–48" range. Anything shorter
  than 24" is hard to use.

Please quote:

1. Per-board-foot price for the spec above.
2. Total for 15 BF, FOB your shipping point.
3. Lead time from order to ship.
4. Photographs of two or three representative boards before payment
   so I can confirm grain orientation and color.

If S4S quartersawn is not available at this volume, please quote for
S2S quartersawn at 5/4 thickness instead and I'll mill to 7/8" myself.

Thanks,
Tony Koop
tonykoop@gmail.com

---

## RFQ tracking

| Field | Value |
|---|---|
| RFQ ID | XYL-RFQ-001 |
| Spec sheet | `bom.csv` row `BAR-STOCK` |
| Sourcing options  | `sourcing.csv` rows for `BAR-STOCK` |
| Sent date | TBD |
| Quote received | TBD |
| Decision | TBD |
| Order placed | TBD |
| Received in shop  | TBD |
| MC at receipt | TBD (target 6–8%; measure on arrival) |

## Decision criteria

Pick the supplier whose quote yields **best (price × delivery × grade
match)**. Bell Forest Products is the default expectation; West Penn
and Cook are the named backups in `sourcing.csv`.

## What to do if no supplier can deliver to spec

Fall-back order: switch the spec's primary species in
`xylophone-design-table.xlsx` from Padauk to Hard Maple (Tier 3 in
`design.md`). Re-run the family table — predicted lengths shift
slightly because Maple's √(E/ρ) is 4229 m/s vs Padauk's 4112. Bars
end up about 1.4% longer. Update `family-spec.csv` and `cut-list.csv`
accordingly.

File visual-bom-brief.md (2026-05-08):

# Xylophone — Visual BOM Brief

Brief for the visual BOM (the recruiter-facing assembly plate). One
page, every line in `bom.csv` represented by a thumbnail and a
two-line label.

## Page layout

- **Header.** Project name + version + quote date + total cost.
- **Hero strip** at top: `images/01-hero.jpg` (or the placeholder
  SVG until captured), full-width.
- **Three columns** of part rows below the hero, top-to-bottom:
  bar stock + finishing on the left, frame stock + hardware in the
  middle, mallets + tuning + measurement gear on the right.
- **Footer.** Total cost, link to the GitHub repo, license note.

## Part-row anatomy

Each row:

```
[thumbnail 60×60]  PART_ID — Part Name
                   Qty • Unit • Estimated cost • Supplier
                   One-line spec summary
```

Thumbnails are pulled from `images/` by part-id slug. When an image
is missing, fall back to a category placeholder (a square with the
part-id text centered, no decoration).

## Mapping bom.csv → visual BOM

| bom.csv part_id | Image slug | Notes for plate |
|---|---|---|
| BAR-STOCK | `images/02-bar-fan.jpg` | top-left, biggest cell |
| FRAME-RAIL | `images/04-frame-elevation.jpg` | use frame photo cropped to rails |
| FRAME-LEG | `images/04-frame-elevation.jpg` | crop to legs |
| FRAME-GUSSET | placeholder square | small detail, use category placeholder |
| CORD-NODE | `images/06-suspension-cord.jpg` | cord visible against bars |
| CORD-WASHER | placeholder square | |
| SCREW-FRAME | placeholder square | |
| GLUE-FRAME | placeholder square | |
| FINISH-OIL | placeholder square | |
| FINISH-WAX | placeholder square | |
| MALLET-HRD | `images/05-mallet-trio.jpg` | crop to hard-rubber mallet |
| MALLET-MED | `images/05-mallet-trio.jpg` | crop to medium yarn mallet |
| TUNER-CHROMA | `images/07-tuner-on-bar.jpg` | OT-120 mid-measurement |
| HYGRO-SHOP | placeholder square | |
| MOIST-METER | `images/09-moisture-meter.jpg` | meter on Padauk end-grain |
| SANDPAPER-KIT | placeholder square | |
| DRILL-BIT-NODE | placeholder square | |
| RESONATOR-TUBE | placeholder square — deferred | grey out the row; v2 build |

## Style

- Black text on white background. No decorative shading.
- Font: Inter or system-ui. Body 9pt, headings 11pt, totals 13pt.
- Print target: US Letter portrait, 0.5" margins. The visual BOM is
  the one page that must be printable in a shop.

## Output

The visual BOM is rendered as part of the print packet
(`print-packet.html` and `print-packet.pdf`). The HTML is the
source of truth; the PDF is generated from it. When optional PDF
deps are missing, the HTML alone is shippable.

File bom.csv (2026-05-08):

part_id | part_name | qty | unit | estimated_cost | supplier_candidate | notes
BAR-STOCK | Padauk 4/4 quartersawn, surfaced 4 sides, KD 6-8% MC | 1 | board-foot-bundle-25 | 180.00 | Bell Forest Products | sized to yield 25 bars 8.3-16.7in long x 1.5in x 7/8in plus 20% waste
FRAME-RAIL | Hard maple 8/4 rail blank 24in x 2.5in x 1.5in | 2 | piece | 28.00 | Bell Forest Products | two suspension rails; rough oversize
FRAME-LEG | Hard maple 8/4 leg blank 32in x 1.75in x 1.75in | 4 | piece | 18.00 | Bell Forest Products | four legs; rough oversize
FRAME-GUSSET | Baltic birch ply 1/2in 12x12 panel | 1 | piece | 14.00 | Lee Valley | two corner gussets per end
CORD-NODE | 1/8 inch paracord black 100ft hank | 1 | hank | 9.00 | Lee Valley | node-suspension cord
CORD-WASHER | Brass finish washer 1/8in cord 25-pack | 1 | pack | 8.00 | Lee Valley | cord termination
SCREW-FRAME | #10 x 2in zinc wood screw 50-pack | 1 | pack | 7.00 | Lee Valley | frame assembly
GLUE-FRAME | Titebond III 16oz | 1 | bottle | 12.00 | Lee Valley | frame joinery
FINISH-OIL | Tung oil pure 16oz | 1 | bottle | 18.00 | Lee Valley | bar and frame finish
FINISH-WAX | Beeswax paste 8oz | 1 | tin | 11.00 | Lee Valley | top coat
MALLET-HRD | Hard rubber xylophone mallet pair | 2 | pair | 32.00 | Innovative Percussion | primary mallet for upper octave
MALLET-MED | Yarn-wrapped medium mallet pair | 2 | pair | 38.00 | Innovative Percussion | alt mallet for low octave
TUNER-CHROMA | Korg OT-120 orchestral tuner | 1 | unit | 140.00 | Sweetwater | validation row 2-8 device of record
HYGRO-SHOP | Combo hygrometer-thermometer digital | 1 | unit | 22.00 | Lee Valley | validation env log
MOIST-METER | Pin-style moisture meter | 1 | unit | 38.00 | Lee Valley | verify 6-8% MC at glue-up
SANDPAPER-KIT | Aluminum oxide grit 80-220 assortment | 1 | kit | 18.00 | Lee Valley | bar surface prep
DRILL-BIT-NODE | 1/8in brad-point bit | 2 | piece | 4.50 | Lee Valley | node-hole drilling, jig-mounted
RESONATOR-TUBE | Aluminum tube 1.5in OD 36in length | 2 | piece | TBD | McMaster-Carr | deferred to v2 build; sized for resonator option

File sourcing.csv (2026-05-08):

part_id | supplier_candidate | required_spec | search_terms | lead_time_days_est | notes
BAR-STOCK | Bell Forest Products | African Padauk 4/4 quartersawn KD to 6-8 percent MC surfaced 4 sides | padauk 4/4 quartersawn KD S4S | 7 | primary; ask for low-shake low-pin selection
BAR-STOCK | West Penn Hardwoods | African Padauk 4/4 quartersawn KD | padauk 4/4 quartersawn | 10 | backup if Bell is OOS
BAR-STOCK | Cook Woods | African Padauk billet selection | padauk billet quartersawn | 14 | third option; pricier but selectable boards
FRAME-RAIL | Bell Forest Products | Hard maple 8/4 KD straight grain | hard maple 8/4 straight grain | 7 | two boards 30in min length
FRAME-LEG | Bell Forest Products | Hard maple 8/4 KD | hard maple 8/4 | 7 | four leg blanks
FRAME-GUSSET | Lee Valley | Baltic birch plywood 1/2in B/BB grade 12x12 | baltic birch 1/2 plywood 12x12 | 5 | or substitute Home Depot if local
CORD-NODE | Lee Valley | Type II 1/8in paracord 100ft | paracord 1/8 100ft | 5 | black or natural
CORD-WASHER | Lee Valley | Brass finish washer fits 1/8in cord | brass finish washer 1/8 cord | 5 | or McMaster-Carr 91068A350
SCREW-FRAME | Lee Valley | #10 x 2in steel wood screw zinc | wood screw #10 2in zinc | 5 | 50-pack minimum
GLUE-FRAME | Lee Valley | Titebond III 16oz | titebond III 16oz | 5 | waterproof PVA, longer open time
FINISH-OIL | Lee Valley | Pure tung oil food-safe 16oz | pure tung oil 16oz | 5 | food-safe so the kid players are fine
FINISH-WAX | Lee Valley | Beeswax paste furniture finish 8oz | beeswax furniture paste 8oz | 5 | top coat over tung
MALLET-HRD | Innovative Percussion | Hard rubber xylophone mallet IP240 or equivalent | IP240 hard rubber xylophone mallet | 7 | alt: Encore EM-1, Vic Firth M134
MALLET-MED | Innovative Percussion | Yarn-wrapped medium marimba mallet | yarn medium marimba mallet pair | 7 | alt: Encore EX-1
TUNER-CHROMA | Sweetwater | Korg OT-120 orchestral tuner | Korg OT-120 orchestral tuner | 3 | or Peterson StroboPlus HD if available
HYGRO-SHOP | Lee Valley | Digital hygrometer thermometer combo | digital hygrometer thermometer shop | 5 | target accuracy +/-3% RH
MOIST-METER | Lee Valley | Pin-style moisture meter wood | pin moisture meter wood | 5 | or General MM50
SANDPAPER-KIT | Lee Valley | Aluminum oxide sanding sheet variety 80-220 grit | aluminum oxide sandpaper variety pack | 5 | hand-sand bar surfaces post-plane
DRILL-BIT-NODE | Lee Valley | Brad point drill bit 1/8in | brad point bit 1/8 inch | 5 | two for spares
RESONATOR-TUBE | McMaster-Carr | 6061 aluminum tube 1.5in OD 0.065in wall 36in | aluminum tube 1.5 OD 0.065 wall | 5 | deferred; quote at v2 build time

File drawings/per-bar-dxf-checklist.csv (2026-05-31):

bar_id | note | target_hz | bar_length_in | bar_width_in | bar_thickness_in | hole_pos_low_in | hole_pos_high_in | expected_dxf_path | required_layers | source_authority | review_status | required_before_fabrication
BAR-C5 | C5 | 523.25 | 16.683 | 1.500 | 0.875 | 3.737 | 12.946 | drawings/dxf/XYL-DR-01-BAR-C5.dxf | FAB_GEOMETRY;DATUM;DIMENSION;NOTES | xylophone-design-table.xlsx + family-spec.csv | measurement_required | Compare exported DXF and extracted CAD dimensions after A5 pilot-bar V2/V3 measurement closes
BAR-Cs5 | C#5 | 554.37 | 16.208 | 1.500 | 0.875 | 3.631 | 12.578 | drawings/dxf/XYL-DR-01-BAR-Cs5.dxf | FAB_GEOMETRY;DATUM;DIMENSION;NOTES | xylophone-design-table.xlsx + family-spec.csv | measurement_required | Compare exported DXF and extracted CAD dimensions after A5 pilot-bar V2/V3 measurement closes
BAR-D5 | D5 | 587.33 | 15.747 | 1.500 | 0.875 | 3.527 | 12.220 | drawings/dxf/XYL-DR-01-BAR-D5.dxf | FAB_GEOMETRY;DATUM;DIMENSION;NOTES | xylophone-design-table.xlsx + family-spec.csv | measurement_required | Compare exported DXF and extracted CAD dimensions after A5 pilot-bar V2/V3 measurement closes
BAR-Ds5 | D#5 | 622.25 | 15.299 | 1.500 | 0.875 | 3.427 | 11.872 | drawings/dxf/XYL-DR-01-BAR-Ds5.dxf | FAB_GEOMETRY;DATUM;DIMENSION;NOTES | xylophone-design-table.xlsx + family-spec.csv | measurement_required | Compare exported DXF and extracted CAD dimensions after A5 pilot-bar V2/V3 measurement closes
BAR-E5 | E5 | 659.26 | 14.863 | 1.500 | 0.875 | 3.329 | 11.534 | drawings/dxf/XYL-DR-01-BAR-E5.dxf | FAB_GEOMETRY;DATUM;DIMENSION;NOTES | xylophone-design-table.xlsx + family-spec.csv | measurement_required | Compare exported DXF and extracted CAD dimensions after A5 pilot-bar V2/V3 measurement closes
BAR-F5 | F5 | 698.46 | 14.440 | 1.500 | 0.875 | 3.235 | 11.205 | drawings/dxf/XYL-DR-01-BAR-F5.dxf | FAB_GEOMETRY;DATUM;DIMENSION;NOTES | xylophone-design-table.xlsx + family-spec.csv | measurement_required | Compare exported DXF and extracted CAD dimensions after A5 pilot-bar V2/V3 measurement closes
BAR-Fs5 | F#5 | 739.99 | 14.029 | 1.500 | 0.875 | 3.142 | 10.886 | drawings/dxf/XYL-DR-01-BAR-Fs5.dxf | FAB_GEOMETRY;DATUM;DIMENSION;NOTES | xylophone-design-table.xlsx + family-spec.csv | measurement_required | Compare exported DXF and extracted CAD dimensions after A5 pilot-bar V2/V3 measurement closes
BAR-G5 | G5 | 783.99 | 13.630 | 1.500 | 0.875 | 3.053 | 10.577 | drawings/dxf/XYL-DR-01-BAR-G5.dxf | FAB_GEOMETRY;DATUM;DIMENSION;NOTES | xylophone-design-table.xlsx + family-spec.csv | measurement_required | Compare exported DXF and extracted CAD dimensions after A5 pilot-bar V2/V3 measurement closes
BAR-Gs5 | G#5 | 830.61 | 13.242 | 1.500 | 0.875 | 2.966 | 10.275 | drawings/dxf/XYL-DR-01-BAR-Gs5.dxf | FAB_GEOMETRY;DATUM;DIMENSION;NOTES | xylophone-design-table.xlsx + family-spec.csv | measurement_required | Compare exported DXF and extracted CAD dimensions after A5 pilot-bar V2/V3 measurement closes
BAR-A5 | A5 | 880.00 | 12.865 | 1.500 | 0.875 | 2.882 | 9.983 | drawings/dxf/XYL-DR-01-BAR-A5.dxf | FAB_GEOMETRY;DATUM;DIMENSION;NOTES | xylophone-design-table.xlsx + family-spec.csv | measurement_required | Compare exported DXF and extracted CAD dimensions after A5 pilot-bar V2/V3 measurement closes
BAR-As5 | A#5 | 932.33 | 12.498 | 1.500 | 0.875 | 2.800 | 9.699 | drawings/dxf/XYL-DR-01-BAR-As5.dxf | FAB_GEOMETRY;DATUM;DIMENSION;NOTES | xylophone-design-table.xlsx + family-spec.csv | measurement_required | Compare exported DXF and extracted CAD dimensions after A5 pilot-bar V2/V3 measurement closes
BAR-B5 | B5 | 987.77 | 12.143 | 1.500 | 0.875 | 2.720 | 9.423 | drawings/dxf/XYL-DR-01-BAR-B5.dxf | FAB_GEOMETRY;DATUM;DIMENSION;NOTES | xylophone-design-table.xlsx + family-spec.csv | measurement_required | Compare exported DXF and extracted CAD dimensions after A5 pilot-bar V2/V3 measurement closes
BAR-C6 | C6 | 1046.50 | 11.797 | 1.500 | 0.875 | 2.643 | 9.154 | drawings/dxf/XYL-DR-01-BAR-C6.dxf | FAB_GEOMETRY;DATUM;DIMENSION;NOTES | xylophone-design-table.xlsx + family-spec.csv | measurement_required | Compare exported DXF and extracted CAD dimensions after A5 pilot-bar V2/V3 measurement closes
BAR-Cs6 | C#6 | 1108.73 | 11.461 | 1.500 | 0.875 | 2.567 | 8.894 | drawings/dxf/XYL-DR-01-BAR-Cs6.dxf | FAB_GEOMETRY;DATUM;DIMENSION;NOTES | xylophone-design-table.xlsx + family-spec.csv | measurement_required | Compare exported DXF and extracted CAD dimensions after A5 pilot-bar V2/V3 measurement closes
BAR-D6 | D6 | 1174.66 | 11.135 | 1.500 | 0.875 | 2.494 | 8.641 | drawings/dxf/XYL-DR-01-BAR-D6.dxf | FAB_GEOMETRY;DATUM;DIMENSION;NOTES | xylophone-design-table.xlsx + family-spec.csv | measurement_required | Compare exported DXF and extracted CAD dimensions after A5 pilot-bar V2/V3 measurement closes
BAR-Ds6 | D#6 | 1244.51 | 10.818 | 1.500 | 0.875 | 2.423 | 8.395 | drawings/dxf/XYL-DR-01-BAR-Ds6.dxf | FAB_GEOMETRY;DATUM;DIMENSION;NOTES | xylophone-design-table.xlsx + family-spec.csv | measurement_required | Compare exported DXF and extracted CAD dimensions after A5 pilot-bar V2/V3 measurement closes
BAR-E6 | E6 | 1318.51 | 10.510 | 1.500 | 0.875 | 2.354 | 8.156 | drawings/dxf/XYL-DR-01-BAR-E6.dxf | FAB_GEOMETRY;DATUM;DIMENSION;NOTES | xylophone-design-table.xlsx + family-spec.csv | measurement_required | Compare exported DXF and extracted CAD dimensions after A5 pilot-bar V2/V3 measurement closes
BAR-F6 | F6 | 1396.91 | 10.211 | 1.500 | 0.875 | 2.287 | 7.923 | drawings/dxf/XYL-DR-01-BAR-F6.dxf | FAB_GEOMETRY;DATUM;DIMENSION;NOTES | xylophone-design-table.xlsx + family-spec.csv | measurement_required | Compare exported DXF and extracted CAD dimensions after A5 pilot-bar V2/V3 measurement closes
BAR-Fs6 | F#6 | 1479.98 | 9.920 | 1.500 | 0.875 | 2.222 | 7.698 | drawings/dxf/XYL-DR-01-BAR-Fs6.dxf | FAB_GEOMETRY;DATUM;DIMENSION;NOTES | xylophone-design-table.xlsx + family-spec.csv | measurement_required | Compare exported DXF and extracted CAD dimensions after A5 pilot-bar V2/V3 measurement closes
BAR-G6 | G6 | 1567.98 | 9.638 | 1.500 | 0.875 | 2.159 | 7.479 | drawings/dxf/XYL-DR-01-BAR-G6.dxf | FAB_GEOMETRY;DATUM;DIMENSION;NOTES | xylophone-design-table.xlsx + family-spec.csv | measurement_required | Compare exported DXF and extracted CAD dimensions after A5 pilot-bar V2/V3 measurement closes
BAR-Gs6 | G#6 | 1661.22 | 9.363 | 1.500 | 0.875 | 2.097 | 7.266 | drawings/dxf/XYL-DR-01-BAR-Gs6.dxf | FAB_GEOMETRY;DATUM;DIMENSION;NOTES | xylophone-design-table.xlsx + family-spec.csv | measurement_required | Compare exported DXF and extracted CAD dimensions after A5 pilot-bar V2/V3 measurement closes
BAR-A6 | A6 | 1760.00 | 9.097 | 1.500 | 0.875 | 2.038 | 7.059 | drawings/dxf/XYL-DR-01-BAR-A6.dxf | FAB_GEOMETRY;DATUM;DIMENSION;NOTES | xylophone-design-table.xlsx + family-spec.csv | measurement_required | Compare exported DXF and extracted CAD dimensions after A5 pilot-bar V2/V3 measurement closes
BAR-As6 | A#6 | 1864.66 | 8.838 | 1.500 | 0.875 | 1.980 | 6.858 | drawings/dxf/XYL-DR-01-BAR-As6.dxf | FAB_GEOMETRY;DATUM;DIMENSION;NOTES | xylophone-design-table.xlsx + family-spec.csv | measurement_required | Compare exported DXF and extracted CAD dimensions after A5 pilot-bar V2/V3 measurement closes
BAR-B6 | B6 | 1975.53 | 8.586 | 1.500 | 0.875 | 1.923 | 6.663 | drawings/dxf/XYL-DR-01-BAR-B6.dxf | FAB_GEOMETRY;DATUM;DIMENSION;NOTES | xylophone-design-table.xlsx + family-spec.csv | measurement_required | Compare exported DXF and extracted CAD dimensions after A5 pilot-bar V2/V3 measurement closes
BAR-C7 | C7 | 2093.00 | 8.342 | 1.500 | 0.875 | 1.869 | 6.473 | drawings/dxf/XYL-DR-01-BAR-C7.dxf | FAB_GEOMETRY;DATUM;DIMENSION;NOTES | xylophone-design-table.xlsx + family-spec.csv | measurement_required | Compare exported DXF and extracted CAD dimensions after A5 pilot-bar V2/V3 measurement closes

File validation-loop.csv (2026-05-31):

check_id | packet_artifact | readiness_before | prediction_source | target | tolerance | method | measured_result | status | next_action | evidence | source_status
XYL-VL-001 | family-spec.csv | L1_packet | free-free Euler-Bernoulli design table | bar pitch predictions are checked against first pilot bar | +/-10 cents rough-cut screen | Cut A5 pilot bar from selected stock and record tuner reading | TBD | measurement_required | Measure A5 before changing the family table | validation.csv:V2 | measurement_required
XYL-VL-002 | validation.csv | L1_packet | tuner measurement protocol | post-shave A5 reaches target fundamental | +/-5 cents | End-shave in 1/64 in increments and log measured_hz plus cents_actual | TBD | measurement_required | Close V3 before treating bar length as bench validated | validation.csv:V3 | measurement_required
XYL-VL-003 | validation.csv | L1_packet | finish drift assumption | finish drift is bounded after oil or wax | -4 to 0 cents | Measure A5 twenty four hours after finish cure | TBD | measurement_required | Record V4 before finalizing finish recommendation | validation.csv:V4 | measurement_required
XYL-VL-004 | family-spec.csv | L1_packet | optional quarter-wave resonator estimate | resonator lengths are treated as planning only until v2 | measurement_required | Build or omit C5-G5 resonators after pilot bar data exists | TBD | measurement_required | Keep resonator_l_in_optional out of fabrication authority for this PR | family-spec.csv | measurement_required
XYL-VL-005 | drawing-brief.md | L1_packet | bar template and design table | bar drawing template traces length and node holes to design table | manual review | Compare drawings/template.svg against family-spec.csv and xylophone-design-table.xlsx | TBD | measurement_required | Generate per-bar drawings only after the template is reviewed | drawing-brief.md | n_a
XYL-VL-006 | cnc/setup-sheet.md | L1_packet | CNC setup plan | bars remain out of CNC scope until measured pilot tuning exists | manual review | Confirm CNC files only cover frame and setup aids before shop release | TBD | measurement_required | Do not create bar toolpaths from first-order estimates | cnc/setup-sheet.md | n_a
XYL-VL-007 | visual-output-register.csv | L1_packet | visual authority register | concept and preview visuals are separated from fabrication authority | validator exits 0 | Run validate_visual_authority.py visual-output-register.csv | TBD | measurement_required | Keep hero and SVG previews non-authoritative | visual-output-register.csv | n_a
XYL-VL-008 | cad/solidworks-master-authority-plan.md | L1_packet | SolidWorks authority plan | CAD master remains unreleased until extracted dimensions match the design table | manual review | Create the master part and extracted-dimension CSV after pilot-bar V2/V3 measurement exists | TBD | measurement_required | Do not list SolidWorks files as fabrication authority until the comparison passes | cad/solidworks-master-authority-plan.md | n_a
XYL-VL-009 | drawings/per-bar-dxf-checklist.csv | L1_packet | per-bar DXF checklist | all 25 bar DXF rows require review before shop release | manual review | Complete every checklist row after CAD/DXF export and visual-register update | TBD | measurement_required | Do not cut bars from DXF exports until all rows are reviewed | drawings/per-bar-dxf-checklist.csv | n_a

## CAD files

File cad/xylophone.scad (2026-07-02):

// Xylophone parametric master — 25-bar chromatic C5-C7 bar field on a
// trestle frame envelope.
//
// Authority: pending_measurement. NOT fabrication authority until reviewed
// against a measured/tuned prototype (see visual-output-register.csv and
// cad/mcp-session-log.md). cad/README.md keeps the SolidWorks master
// deferred until pilot-bar V2 measurements exist; this OpenSCAD file is a
// planning envelope only, not a replacement for that gate.
//
// SCOPE BOUNDARY: this models the bar LENGTH schedule (flat rectangular
// bars, per-bar length/width/thickness and node-hole positions, all taken
// directly from family-spec.csv) plus a trestle-frame envelope. It does NOT
// model bar arch/tuning geometry (this xylophone is explicitly flat-bottom,
// end-shaved for tuning by hand — "no arch undercut, that's marimba" per
// design.md) and does NOT model resonator tubes (design.md: "computed but
// optional... not fabrication authority in this packet").
//
// Dimension sources (do not edit values without updating the source record):
//   - bar_schedule: family-spec.csv (25 rows) — bar_length_in, bar_width_in,
//     bar_thickness_in, hole_pos_low_in, hole_pos_high_in per note. Formula
//     cited there: free-free Euler-Bernoulli f1 = 1.028*(h/L^2)*sqrt(E/rho),
//     Padauk E=12.6 GPa, rho=745 kg/m3.
//   - frame rail/leg dimensions: cut-list.csv RAIL-L/R, LEG-FL/FR/RL/RR
//     (finished dims column)
//   - bar spacing / fan layout: design.md "Frame Layout" (single bar fan,
//     rail length = max(family-spec L) + 4in margin, rounded to 21in)
//
// Units: inches.

/* [Frame] */
rail_length_in      = 21.000; // cut-list.csv RAIL-L/R finished length
rail_width_in       = 2.250;  // cut-list.csv RAIL-L/R finished width (top face)
rail_thickness_in   = 1.250;  // cut-list.csv RAIL-L/R finished thickness
leg_height_in       = 30.000; // cut-list.csv LEG-* finished length (standing-play height)
leg_side_in         = 1.500;  // cut-list.csv LEG-* finished cross-section (square)
rail_spacing_in     = 16.0;   // ASSUMPTION: distance between rail centerlines along bar length;
                               // not explicitly given in design.md/cut-list.csv beyond node-hole
                               // positions (22.4%/77.6% of bar L) — legs sit inboard of the rail ends.

/* [Bar field layout] */
bar_gap_in          = 0.125;  // ASSUMPTION: visual/clearance gap between adjacent bars in the fan;
                               // not specified in design.md (bars are individually end-shaved and
                               // cord-suspended, not edge-to-edge fixed) — planning spacing only.

/* [Render quality] */
$fn = 48;

// ---------------------------------------------------------------------------
// Bar schedule — family-spec.csv, C5 (first/longest) through C7 (last/shortest)
// [note, target_hz, length_in, width_in, thickness_in, hole_low_in, hole_high_in]
// ---------------------------------------------------------------------------

bar_schedule = [
    ["C5",   523.25, 16.683, 1.500, 0.875,  3.737, 12.946],
    ["C#5",  554.37, 16.208, 1.500, 0.875,  3.631, 12.578],
    ["D5",   587.33, 15.747, 1.500, 0.875,  3.527, 12.220],
    ["D#5",  622.25, 15.299, 1.500, 0.875,  3.427, 11.872],
    ["E5",   659.26, 14.863, 1.500, 0.875,  3.329, 11.534],
    ["F5",   698.46, 14.440, 1.500, 0.875,  3.235, 11.205],
    ["F#5",  739.99, 14.029, 1.500, 0.875,  3.142, 10.886],
    ["G5",   783.99, 13.630, 1.500, 0.875,  3.053, 10.577],
    ["G#5",  830.61, 13.242, 1.500, 0.875,  2.966, 10.275],
    ["A5",   880.00, 12.865, 1.500, 0.875,  2.882,  9.983],
    ["A#5",  932.33, 12.498, 1.500, 0.875,  2.800,  9.699],
    ["B5",   987.77, 12.143, 1.500, 0.875,  2.720,  9.423],
    ["C6",  1046.50, 11.797, 1.500, 0.875,  2.643,  9.154],
    ["C#6", 1108.73, 11.461, 1.500, 0.875,  2.567,  8.894],
    ["D6",  1174.66, 11.135, 1.500, 0.875,  2.494,  8.641],
    ["D#6", 1244.51, 10.818, 1.500, 0.875,  2.423,  8.395],
    ["E6",  1318.51, 10.510, 1.500, 0.875,  2.354,  8.156],
    ["F6",  1396.91, 10.211, 1.500, 0.875,  2.287,  7.923],
    ["F#6", 1479.98,  9.920, 1.500, 0.875,  2.222,  7.698],
    ["G6",  1567.98,  9.638, 1.500, 0.875,  2.159,  7.479],
    ["G#6", 1661.22,  9.363, 1.500, 0.875,  2.097,  7.266],
    ["A6",  1760.00,  9.097, 1.500, 0.875,  2.038,  7.059],
    ["A#6", 1864.66,  8.838, 1.500, 0.875,  1.980,  6.858],
    ["B6",  1975.53,  8.586, 1.500, 0.875,  1.923,  6.663],
    ["C7",  2093.00,  8.342, 1.500, 0.875,  1.869,  6.473],
];

// ---------------------------------------------------------------------------
// Frame — 4-leg trestle, two suspension rails
// ---------------------------------------------------------------------------

module rail(x_offset_in) {
    translate([0, x_offset_in, leg_height_in])
        cube([rail_length_in, rail_thickness_in, rail_width_in]);
}

module leg(x_in, y_in) {
    translate([x_in, y_in, 0])
        cube([leg_side_in, leg_side_in, leg_height_in]);
}

module frame() {
    // Two rails running the length of the bar fan (X axis), spaced along Y.
    rail(0);
    rail(rail_spacing_in);
    // Four legs near the rail ends.
    leg(leg_side_in / 2, -leg_side_in / 2);
    leg(rail_length_in - leg_side_in * 1.5, -leg_side_in / 2);
    leg(leg_side_in / 2, rail_spacing_in + rail_thickness_in - leg_side_in / 2);
    leg(rail_length_in - leg_side_in * 1.5, rail_spacing_in + rail_thickness_in - leg_side_in / 2);
}

// ---------------------------------------------------------------------------
// Bar field — flat rectangular bars, node-hole markers, laid out in fan order
// ---------------------------------------------------------------------------

bar_top_z_in = leg_height_in + rail_width_in; // bars rest on top of the rails

module bar(length_in, width_in, thickness_in, hole_low_in, hole_high_in) {
    difference() {
        cube([length_in, width_in, thickness_in]);
        // Node holes for 1/8" paracord suspension, at the free-free first-mode
        // node fractions (~22.4% / 77.6% of length), positions from family-spec.csv.
        translate([hole_low_in, width_in / 2, -0.1])
            cylinder(h = thickness_in + 0.2, d = 0.125);
        translate([hole_high_in, width_in / 2, -0.1])
            cylinder(h = thickness_in + 0.2, d = 0.125);
    }
}

module bar_field() {
    y_cursor = 0;
    for (i = [0:len(bar_schedule) - 1]) {
        b = bar_schedule[i];
        length_in = b[2];
        width_in = b[3];
        thickness_in = b[4];
        hole_low_in = b[5];
        hole_high_in = b[6];
        // Center each bar's length over the rail span; step across Y by bar width + gap.
        y_pos = i * (width_in + bar_gap_in);
        x_pos = (rail_length_in - length_in) / 2;
        translate([x_pos, y_pos, bar_top_z_in])
            bar(length_in, width_in, thickness_in, hole_low_in, hole_high_in);
    }
}

// ---------------------------------------------------------------------------
// Top-level assembly
// ---------------------------------------------------------------------------

module xylophone_master() {
    frame();
    bar_field();
}

xylophone_master();

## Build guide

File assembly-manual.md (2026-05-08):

# Xylophone — Assembly Manual

14 shop steps, in order. Checkboxes are blank for shop use; tick them
off as you go. Estimated total bench time: **3 working days** with
overnight glue cures.

## Materials and tools required

Read `bom.csv` and `sourcing.csv` end-to-end before starting. The
critical-path items: Padauk bar stock at 6–8% MC, Korg OT-120 tuner,
1/8" brad-point bit, Titebond III, tung oil, and the two jigs from
`jig-decision.md` (node-hole drilling jig, end-shaving sled).

## Step 1 — Verify moisture content

- [ ] Pin-meter the Padauk bar stock at three points along each
  board. Target 6.0–8.0% MC.
- [ ] Log temp + RH in the shop in `validation.csv` row V1.
- [ ] If MC > 8%: stack with stickers in the shop for two weeks and
  remeasure. **Do not proceed until MC is 6–8%.**

## Step 2 — Mill blanks to rough cut-list dimensions

- [ ] Cross-cut each bar blank to its `rough_dimensions_in[0]` length
  (per `cut-list.csv`). Add 1" to the longest blanks for safety.
- [ ] Rip to 1.625" rough width.
- [ ] Joint one face and one edge.
- [ ] Plane to 1.0" rough thickness.

## Step 3 — Final mill bars

- [ ] Plane to **0.875"** final thickness.
- [ ] Rip to **1.500"** final width.
- [ ] Cross-cut to the `final_dimensions_in[0]` length per
  `cut-list.csv`. **Cut long by 1/16"** — final length is set in
  the tuning step.

## Step 4 — Surface prep

- [ ] Drum-sand or hand-sand each bar 80 → 120 → 180 → 220.
- [ ] Ease all four long edges with a 1/16" round-over.
- [ ] Mark each bar's note name on the underside in pencil.

## Step 5 — Drill node holes (jig)

- [ ] Set up the node-hole drilling jig from `jig-decision.md`.
- [ ] For each bar: set both flip-stops to the bar's
  `hole_pos_low_in` and `hole_pos_high_in` from `family-spec.csv`.
- [ ] Drill the low-side hole, flip stops, drill the high-side hole.
- [ ] Chamfer both holes ~0.5mm with a countersink to prevent cord
  chafing.

## Step 6 — First measurement

- [ ] Suspend each bar from a piece of test-cord through both node
  holes.
- [ ] Strike with the hard rubber mallet, measure with the Korg
  OT-120.
- [ ] Log result for each bar in `validation.csv` row V2.
- [ ] **Expected outcome:** bars read 5–25 cents *low* of target.
  This is normal — final length is shaved in the next step.

## Step 7 — Tune by end-shaving

- [ ] On the end-shaving sled: shave equal amounts from each bar end
  in 1/64" increments. Symmetric shaving keeps the node positions
  centered.
- [ ] After each pass, re-suspend, re-strike, re-measure. Stop when
  cents-actual is within ±2 cents of target.
- [ ] Log result in `validation.csv` row V3.
- [ ] If a bar overshoots (reads sharp): **do not add material**.
  Either accept the +cents or scrap the bar.

## Step 8 — Mill frame parts

- [ ] Mill the two suspension rails to `21.000 × 2.250 × 1.250"`.
- [ ] Mill four legs to `30.000 × 1.500 × 1.500"`. Chamfer the top
  edge of each leg to clear the suspension cord.
- [ ] Cut four corner gussets from 1/2" Baltic birch plywood at
  `6.000 × 6.000"`, hypotenuse to hypotenuse (i.e., 45-degree
  triangles).

## Step 9 — Frame dry-fit

- [ ] Dry-assemble the frame: legs into rails via the gussets.
- [ ] Verify rail-to-rail spacing is 6.5" inside-to-inside (matches
  the bar width plus suspension margin).
- [ ] Verify legs are square to rails.

## Step 10 — Frame glue-up

- [ ] Apply Titebond III to all gusset-to-frame joints.
- [ ] Drive #10 × 2" wood screws through pilot holes (Padauk and
  hard maple both want pilots).
- [ ] Clamp 24 hours. Do not flex the frame during cure.

## Step 11 — Apply finish

- [ ] Wipe each bar with mineral spirits to remove sanding dust.
- [ ] Apply pure tung oil with a lint-free rag, three coats. Each
  coat dries 24 hours; sand lightly between coats with 320.
- [ ] Apply finish to the frame the same way (two coats is enough).
- [ ] **24 hours after the last bar coat:** re-measure each bar.
  Log in `validation.csv` row V4. Expected drift: −2 to −4 cents
  from finish mass loading. If drift exceeds −5 cents, end-shave
  again to compensate.

## Step 12 — Top-coat and cure

- [ ] Apply beeswax paste over the cured tung oil; buff out.
- [ ] Allow seven days at shop ambient before play-testing.

## Step 13 — Suspend bars

- [ ] Cut paracord to length: rail length × 2 + 12" tail per rail.
- [ ] Tie a stopper knot at each rail end.
- [ ] Thread cord through node holes in C5–C7 order, alternating
  bar-to-cord-to-bar.
- [ ] Terminate at the second rail with brass finish washers and a
  tied loop.

## Step 14 — Final validation

- [ ] Photograph the finished assembly per `photo-shotlist.md`
  shots 1, 2, 4, 5, 6, 7, 10.
- [ ] Run validation row V8 (full-octave evenness): measure C5, C6,
  C7 in one session. Document spread.
- [ ] Schedule validation rows V6 (30-day) and V7 (60-day) on the
  shop calendar.
- [ ] Mark this packet as `built` in the master catalog.

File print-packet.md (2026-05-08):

# Xylophone Capstone Print Packet

Generated: 2026-05-08
Packet folder: `/mnt/c/Users/Tony/Documents/GitHub/xylophone`

## File Map

| File | Purpose |
| --- | --- |
| `design.md` | Project intent, catalog metadata, assumptions, and validation plan. |
| `bom.csv` | Starter bill of materials with part categories, quantities, drawing refs, and notes. |
| `sourcing.csv` | Supplier/search tracker with specs, price/date fields, lead time, substitutes, and risks. |
| `cut-list.csv` | Rough/final stock sizes, material, grain/orientation, operations, yield, and offcuts. |
| `drawing-brief.md` | Manufacturing drawing and technical product sketch brief. |
| `assembly-manual.md` | Shop-facing sequence, tools, fixtures, safety, tuning, finishing, and maintenance notes. |
| `validation.csv` | Target/measured values, tolerance, environment, result, and tuning/build action log. |
| `supplier-rfq.md` | Supplier email/request-for-quote starter. |
| `visual-bom-brief.md` | Art direction for an image-forward visual BOM. |
| `wolfram-starter.wl` | Wolfram starter for physics, optimization, visualization, and validation. |
| `README.md` | Project artifact. |
| `family-spec.csv` | Project artifact. |
| `jig-decision.md` | Project artifact. |
| `photo-shotlist.md` | Project artifact. |
| `resources.md` | Project artifact. |
| `risks.md` | Project artifact. |

## design.md

Project intent, catalog metadata, assumptions, and validation plan.

# Xylophone — Design

A 25-bar chromatic xylophone, C5 to C7, in Padauk on a parametric trestle frame.
Free-free flat-bar geometry, 12th-overtone tuning convention, optional
quarter-wave closed-pipe resonators (deferred). Designed deliberately as the
*simpler* sibling of a future marimba sister repo: every place this design
chooses the simpler path, the marimba-equivalent is documented inline so the
marimba scaffold inherits cleanly.

## Intent

Ship a parametric, validator-clean, public-readable Mode A build packet for
a serious wooden tuned-bar idiophone — small enough to build in one shop
session, honest enough about the physics that the predicted frequencies and
the measured frequencies will disagree on first cut and the workflow can
correct them, structured enough that a marimba follow-on can reuse the
family table, the validation rows, the suspension geometry, the SolidWorks
master-layout convention, and the empirical-correction guard rules.

The reader should leave with: (a) a parametric design table whose inputs
are wood species, bar thickness, target pitch, and frame geometry; (b) a
defensible first-order frequency prediction per note; (c) a measured-tuning
workflow that closes the loop on the prediction; (d) a clear "this is what
turns into marimba next" map.

## Governing Model

Free-free Euler-Bernoulli transverse beam vibration, first mode:

    f_1 = 1.028 × (h / L²) × √(E / ρ)

Symbols and units (SI):

- `h` — bar thickness (m)
- `L` — bar length (m)
- `E` — Young's modulus along grain (Pa)
- `ρ` — density (kg/m³)
- `f_1` — first-mode frequency (Hz)

Reference: `acoustic-models.md` Free-Free Beams section. The formula
follows from `K_free_free ≈ 6.36 × K_cantilever` applied to the
cantilever form `f_1 ≈ 0.162 × (h/L²) × √(E/ρ)`. Suspension nodes for
the first free-free mode are at **22.4% and 77.6% of L** — every
cord-hole in `family-spec.csv` is placed there.

**First-order estimate caveat.** Per the `acoustic-models.md`
empirical-correction guard rules, K2 corrections, scale-offset tables,
and end-corrections **do not apply** to bar idiophones. Material
K-constants from the cantilever wood table are species-specific and
only valid for the free-free / fixed-free regime — they propagate to
this packet via the 6.36× factor above. Every predicted frequency in
`family-spec.csv` is flagged as *first-order*; `validation.csv` is the
mechanism that closes the gap with measured data after first prototype.

**Xylophone tuning convention.** Bars are tuned to align the *12th
overtone* (3:1 frequency ratio above the fundamental — actually the
second flexural mode tuned to a perfect 12th of the fundamental in the
concert convention; first-order math reports `f_1` only). Marimba
tunes the second mode to a 4:1 ratio (two octaves) by parabolic arch
undercut. **This packet uses no arch undercut** — bars are flat-bottom
rectangular blanks, end-shaved for fundamental tuning. The
12th-overtone target is documented as a *measurement target* in
`validation.csv`, not a CAD geometry — adjust at the bench.

> Marimba-equivalent: replace the flat-bottom geometry with a parabolic
> CNC arch on the underside (`acoustic-models.md`:
> `center_thickness = edge_thickness × (target_freq / flat_bar_freq)²`,
> minimum center 0.25"). Replace the 12th-overtone target with the
> 4:1 octave-and-a-fifth target. Replace the optional resonators with
> mandatory tuned tubes.

## Family Plan

Two octaves chromatic, C5 to C7, 25 bars. Family geometry held
constant: bar width `W = 1.500"`, bar thickness `h = 0.875"` (7/8"
flat stock). Only `L` varies — solved per note from the governing
model. See `family-spec.csv` for the full table.

Predicted lengths run from **16.683" at C5** to **8.342" at C7**.
These are noticeably longer than a concert xylophone of the same
range because the design has no arch undercut — the arch is what
lets a concert xylo hit the same pitch with a 10–12" bar. The
flat-bar tradeoff is honest, parametric, and easier to first-cut.

Width and thickness are constants in this v1 family. Production
xylophones often taper width across the range; that's a deferred
optimization, called out in Open Assumptions.

> Marimba-equivalent: keep width constant within an octave but step
> width up at register boundaries (low marimba bars are wider). Add an
> arch-depth column. Add a resonator-tube-bore column.

## Wood Species

Three-tier shortlist; **Padauk is the spec's primary** because it is
sustainably sourced, has predictable acoustic properties, machines
cleanly, and is widely available in 4/4 quartersawn:

| Tier | Species | E (GPa) | ρ (kg/m³) | √(E/ρ) (m/s) | Notes |
|---|---|---|---|---|---|
| Primary | African Padauk | 12.6 | 745 | 4112 | Spec default. Stable, predictable, sustainable. |
| Traditional | Honduras Rosewood | 14.1 | 1000 | 3756 | Concert standard. **CITES II** — sourcing risk. |
| Educational/budget| Hard Maple | 12.6 | 705 | 4229 | Cheapest, most available, dampest sound. |

Switching the primary requires a single edit in
`xylophone-design-table.xlsx` (input cell `wood_species`); the family
table re-solves automatically. The validator runs on the table's
current state, not on a hardcoded snapshot.

> Marimba-equivalent: same shortlist, but most concert marimbas use
> Padauk or Honduras Rosewood; Birch is the educational tier.

## Tuning Workflow

The validation loop has eight rows in `validation.csv`. Two are
prediction-only; six require a tuner and a chromatic environment log:

1. Rough-cut prediction (paper, before any cut).
2. Post-cut fundamental measurement (immediately after bandsaw + plane).
3. Post-shave measurement (after end-shaving for fundamental tune).
4. Post-finish measurement (after oil/wax — finish adds mass, drops pitch).
5. Post-resonator-install measurement (when resonators are installed; deferred).
6. 30-day moisture re-measure (drift after first shop cycle).
7. 60-day moisture re-measure (drift after a full season cycle).
8. Full-octave evenness check (every C across both octaves on the same day).

Each row carries `tuner_make_model`, `temp_F`, `humidity_RH_percent`,
and `cents_target` columns matching `record_measurement.py`'s schema.
A measured Hz feeds `record_measurement.py --packet . --note-id <X>
--measured-hz <f>` and the per-family corrections database absorbs
the delta.

## Resonator Decision

**Optional, deferred to v2 build.** The L-per-note math is computed
in `family-spec.csv` (column `resonator_l_in_optional`) using the
quarter-wave closed-pipe formula with end correction:

    L_resonator = c / (4 f) − 0.82 × bore

with `c = 343 m/s` and `bore = 1.500"`. Lengths run from **5.22" at
C5** down to **0.38" at C7**. The high-end values are too short to
build practically — the production decision will be: tune resonators
on bars at C5 through approximately G5 (lengths > 3"), and skip
resonators on the upper octave. This decision is made when resonators
are installed, not now.

> Marimba-equivalent: resonators are mandatory; the bore is bigger
> (typically 2.0–3.0"); each tube is plugged at the bottom and tuned
> at the top end. Marimba tubes are also typically *not* trimmed by
> the 0.82×bore end-correction directly — they're trimmed by ear at
> the bench.

## Frame Layout

4-leg parametric trestle frame, two suspension rails running the full
length of the bar fan. Rail length sized to `max(family-spec L) +
4" margin = 16.683 + 4 = 20.683"` rounded up to **21"**. Leg
height **30"** (standard standing-play height; sit-down play needs
a swap to 24"). Cord suspension with `1/8"` paracord through the
node holes; cord termination at the rail ends with a tied-loop and
finish washer.

Frame parts are CNC candidates (rails, leg blanks, gussets) — see
`cnc/operations.csv`. Bars are explicitly out of CNC scope: bandsaw
to rough → surface plane to thickness → drum-sand surfaces → drill
node holes (jig) → end-shave for tuning (manual). The CNC plan
states this exclusion in the setup sheet.

> Marimba-equivalent: longer frame (4-octave marimba is 5+ feet),
> resonator wells underneath each bar pair, height-adjustable legs,
> traveling-cart casters.

## Mallets

Hard rubber → lexan → rosewood-head shortlist. Hard mallets are
appropriate for xylophone (the percussive, glassy attack is part of
the instrument's voice). They are **harder than marimba mallets**
and *can* crack a softer-wood bar — see `risks.md` entry
`bar-cracking-from-hard-mallets`. Standard practice: yarn-wrapped
mallets for low octave, lexan/rubber for upper. v1 packet ships with
hard rubber as the recommended starter; lexan and rosewood are
swap-ins.

> Marimba-equivalent: yarn-wrapped soft mallets across the entire
> range. The bars are softer (Honduras Rosewood is a hardwood but
> with arch undercut the center is thin); soft mallets prevent
> cracking and produce a warmer overtone profile.

## Marimba-Equivalent Hooks (summary map)

| Decision | Xylophone (this packet) | Marimba (sister repo, deferred) |
|---|---|---|
| Bar geometry | Flat-bottom rectangular | Parabolic arch undercut on underside |
| Tuning ratio target | 12th overtone (3:1) | 4:1 (two octaves) |
| Resonators | Optional, deferred | Mandatory, tuned per bar |
| Bar width policy | Constant 1.500" across range | Step up at register boundaries |
| Mallet hardness | Hard rubber → lexan → rosewood | Yarn-wrapped soft → medium |
| Suspension cord | 1/8" paracord | 3/16" or 1/4" (heavier bars) |
| Frame length | 21" rail | 60"+ rail, multi-octave |
| Wood primary | Padauk | Padauk or Honduras Rosewood |

A future `marimba/` repo can `cp -r xylophone/* marimba/` and edit
exactly these eight rows in the design table to bootstrap.

## Open Assumptions

1. **No measured data yet.** Every frequency in `family-spec.csv` is a
   first-order prediction. First measurement after first prototype is
   the single most important next step. (`validation.csv` row 2.)
2. **Wood species.** Padauk is the primary by spec choice; Honduras
   Rosewood and Hard Maple swap in by changing one cell in the
   workbook. CITES sourcing for HR is not analyzed in this packet.
3. **Family range.** C5–C7 chromatic is the chosen default. F4–F6
   diatonic and G4–G6 diatonic remain documented alternatives — they
   trade range for shorter bar stock and a smaller frame.
4. **Bar thickness held constant at 7/8".** A real production xylo
   often steps thickness up in the low octave to keep bars from being
   absurdly long. This packet keeps thickness constant for parametric
   simplicity and accepts the 16.7" C5 bar.
5. **Resonator strategy.** The L-per-note math is computed but
   resonators are not specified in the BOM. Adding them is additive,
   not breaking — the frame design leaves vertical clearance.
6. **CAD.** SolidWorks master-layout part is deferred; the
   `cad/` folder has a stub README pointing at the tongue-drum
   convention and the existing `xylophone-design-table.xlsx`.
7. **Mallet supplier.** v1 lists generic hard-rubber mallets; specific
   supplier (Innovative Percussion vs Encore vs Vic Firth) is not
   selected.

These eight rows are exactly the assumptions the handoff report
flags. Each becomes a `validation.csv` or `bom.csv` line item once
the gating decision is made.

## bom.csv

Starter bill of materials with part categories, quantities, drawing refs, and notes.

| part_id | part_name | qty | unit | estimated_cost | supplier_candidate | notes |
| --- | --- | --- | --- | --- | --- | --- |
| BAR-STOCK | Padauk 4/4 quartersawn, surfaced 4 sides, KD 6-8% MC | 1 | board-foot-bundle-25 | 180.00 | Bell Forest Products | sized to yield 25 bars 8.3-16.7in long x 1.5in x 7/8in plus 20% waste |
| FRAME-RAIL | Hard maple 8/4 rail blank 24in x 2.5in x 1.5in | 2 | piece | 28.00 | Bell Forest Products | two suspension rails; rough oversize |
| FRAME-LEG | Hard maple 8/4 leg blank 32in x 1.75in x 1.75in | 4 | piece | 18.00 | Bell Forest Products | four legs; rough oversize |
| FRAME-GUSSET | Baltic birch ply 1/2in 12x12 panel | 1 | piece | 14.00 | Lee Valley | two corner gussets per end |
| CORD-NODE | 1/8 inch paracord black 100ft hank | 1 | hank | 9.00 | Lee Valley | node-suspension cord |
| CORD-WASHER | Brass finish washer 1/8in cord 25-pack | 1 | pack | 8.00 | Lee Valley | cord termination |
| SCREW-FRAME | #10 x 2in zinc wood screw 50-pack | 1 | pack | 7.00 | Lee Valley | frame assembly |
| GLUE-FRAME | Titebond III 16oz | 1 | bottle | 12.00 | Lee Valley | frame joinery |
| FINISH-OIL | Tung oil pure 16oz | 1 | bottle | 18.00 | Lee Valley | bar and frame finish |
| FINISH-WAX | Beeswax paste 8oz | 1 | tin | 11.00 | Lee Valley | top coat |
| MALLET-HRD | Hard rubber xylophone mallet pair | 2 | pair | 32.00 | Innovative Percussion | primary mallet for upper octave |
| MALLET-MED | Yarn-wrapped medium mallet pair | 2 | pair | 38.00 | Innovative Percussion | alt mallet for low octave |
| TUNER-CHROMA | Korg OT-120 orchestral tuner | 1 | unit | 140.00 | Sweetwater | validation row 2-8 device of record |
| HYGRO-SHOP | Combo hygrometer-thermometer digital | 1 | unit | 22.00 | Lee Valley | validation env log |
| MOIST-METER | Pin-style moisture meter | 1 | unit | 38.00 | Lee Valley | verify 6-8% MC at glue-up |
| SANDPAPER-KIT | Aluminum oxide grit 80-220 assortment | 1 | kit | 18.00 | Lee Valley | bar surface prep |
| DRILL-BIT-NODE | 1/8in brad-point bit | 2 | piece | 4.50 | Lee Valley | node-hole drilling, jig-mounted |
| RESONATOR-TUBE | Aluminum tube 1.5in OD 36in length | 2 | piece | TBD | McMaster-Carr | deferred to v2 build; sized for resonator option |

## sourcing.csv

Supplier/search tracker with specs, price/date fields, lead time, substitutes, and risks.

| part_id | supplier_candidate | required_spec | search_terms | lead_time_days_est | notes |
| --- | --- | --- | --- | --- | --- |
| BAR-STOCK | Bell Forest Products | African Padauk 4/4 quartersawn KD to 6-8 percent MC surfaced 4 sides | padauk 4/4 quartersawn KD S4S | 7 | primary; ask for low-shake low-pin selection |
| BAR-STOCK | West Penn Hardwoods | African Padauk 4/4 quartersawn KD | padauk 4/4 quartersawn | 10 | backup if Bell is OOS |
| BAR-STOCK | Cook Woods | African Padauk billet selection | padauk billet quartersawn | 14 | third option; pricier but selectable boards |
| FRAME-RAIL | Bell Forest Products | Hard maple 8/4 KD straight grain | hard maple 8/4 straight grain | 7 | two boards 30in min length |
| FRAME-LEG | Bell Forest Products | Hard maple 8/4 KD | hard maple 8/4 | 7 | four leg blanks |
| FRAME-GUSSET | Lee Valley | Baltic birch plywood 1/2in B/BB grade 12x12 | baltic birch 1/2 plywood 12x12 | 5 | or substitute Home Depot if local |
| CORD-NODE | Lee Valley | Type II 1/8in paracord 100ft | paracord 1/8 100ft | 5 | black or natural |
| CORD-WASHER | Lee Valley | Brass finish washer fits 1/8in cord | brass finish washer 1/8 cord | 5 | or McMaster-Carr 91068A350 |
| SCREW-FRAME | Lee Valley | #10 x 2in steel wood screw zinc | wood screw #10 2in zinc | 5 | 50-pack minimum |
| GLUE-FRAME | Lee Valley | Titebond III 16oz | titebond III 16oz | 5 | waterproof PVA, longer open time |
| FINISH-OIL | Lee Valley | Pure tung oil food-safe 16oz | pure tung oil 16oz | 5 | food-safe so the kid players are fine |
| FINISH-WAX | Lee Valley | Beeswax paste furniture finish 8oz | beeswax furniture paste 8oz | 5 | top coat over tung |
| MALLET-HRD | Innovative Percussion | Hard rubber xylophone mallet IP240 or equivalent | IP240 hard rubber xylophone mallet | 7 | alt: Encore EM-1, Vic Firth M134 |
| MALLET-MED | Innovative Percussion | Yarn-wrapped medium marimba mallet | yarn medium marimba mallet pair | 7 | alt: Encore EX-1 |
| TUNER-CHROMA | Sweetwater | Korg OT-120 orchestral tuner | Korg OT-120 orchestral tuner | 3 | or Peterson StroboPlus HD if available |
| HYGRO-SHOP | Lee Valley | Digital hygrometer thermometer combo | digital hygrometer thermometer shop | 5 | target accuracy +/-3% RH |
| MOIST-METER | Lee Valley | Pin-style moisture meter wood | pin moisture meter wood | 5 | or General MM50 |
| SANDPAPER-KIT | Lee Valley | Aluminum oxide sanding sheet variety 80-220 grit | aluminum oxide sandpaper variety pack | 5 | hand-sand bar surfaces post-plane |
| DRILL-BIT-NODE | Lee Valley | Brad point drill bit 1/8in | brad point bit 1/8 inch | 5 | two for spares |
| RESONATOR-TUBE | McMaster-Carr | 6061 aluminum tube 1.5in OD 0.065in wall 36in | aluminum tube 1.5 OD 0.065 wall | 5 | deferred; quote at v2 build time |

## cut-list.csv

Rough/final stock sizes, material, grain/orientation, operations, yield, and offcuts.

| part_id | part_name | qty | rough_dimensions_in | final_dimensions_in | grain_orientation | notes |
| --- | --- | --- | --- | --- | --- | --- |
| BAR-C5 | Bar C5 | 1 | 18.0 x 1.625 x 1.0 | 16.683 x 1.500 x 0.875 | longitudinal-quarter | longest bar; cut from longest blank |
| BAR-Cs5 | Bar C#5 | 1 | 17.5 x 1.625 x 1.0 | 16.208 x 1.500 x 0.875 | longitudinal-quarter |  |
| BAR-D5 | Bar D5 | 1 | 17.0 x 1.625 x 1.0 | 15.747 x 1.500 x 0.875 | longitudinal-quarter |  |
| BAR-Ds5 | Bar D#5 | 1 | 16.5 x 1.625 x 1.0 | 15.299 x 1.500 x 0.875 | longitudinal-quarter |  |
| BAR-E5 | Bar E5 | 1 | 16.0 x 1.625 x 1.0 | 14.863 x 1.500 x 0.875 | longitudinal-quarter |  |
| BAR-F5 | Bar F5 | 1 | 15.5 x 1.625 x 1.0 | 14.440 x 1.500 x 0.875 | longitudinal-quarter |  |
| BAR-Fs5 | Bar F#5 | 1 | 15.0 x 1.625 x 1.0 | 14.029 x 1.500 x 0.875 | longitudinal-quarter |  |
| BAR-G5 | Bar G5 | 1 | 15.0 x 1.625 x 1.0 | 13.630 x 1.500 x 0.875 | longitudinal-quarter |  |
| BAR-Gs5 | Bar G#5 | 1 | 14.5 x 1.625 x 1.0 | 13.242 x 1.500 x 0.875 | longitudinal-quarter |  |
| BAR-A5 | Bar A5 | 1 | 14.0 x 1.625 x 1.0 | 12.865 x 1.500 x 0.875 | longitudinal-quarter |  |
| BAR-As5 | Bar A#5 | 1 | 13.5 x 1.625 x 1.0 | 12.498 x 1.500 x 0.875 | longitudinal-quarter |  |
| BAR-B5 | Bar B5 | 1 | 13.5 x 1.625 x 1.0 | 12.143 x 1.500 x 0.875 | longitudinal-quarter |  |
| BAR-C6 | Bar C6 | 1 | 13.0 x 1.625 x 1.0 | 11.797 x 1.500 x 0.875 | longitudinal-quarter |  |
| BAR-Cs6 | Bar C#6 | 1 | 12.5 x 1.625 x 1.0 | 11.461 x 1.500 x 0.875 | longitudinal-quarter |  |
| BAR-D6 | Bar D6 | 1 | 12.5 x 1.625 x 1.0 | 11.135 x 1.500 x 0.875 | longitudinal-quarter |  |
| BAR-Ds6 | Bar D#6 | 1 | 12.0 x 1.625 x 1.0 | 10.818 x 1.500 x 0.875 | longitudinal-quarter |  |
| BAR-E6 | Bar E6 | 1 | 11.5 x 1.625 x 1.0 | 10.510 x 1.500 x 0.875 | longitudinal-quarter |  |
| BAR-F6 | Bar F6 | 1 | 11.5 x 1.625 x 1.0 | 10.211 x 1.500 x 0.875 | longitudinal-quarter |  |
| BAR-Fs6 | Bar F#6 | 1 | 11.0 x 1.625 x 1.0 | 9.920 x 1.500 x 0.875 | longitudinal-quarter |  |
| BAR-G6 | Bar G6 | 1 | 10.5 x 1.625 x 1.0 | 9.638 x 1.500 x 0.875 | longitudinal-quarter |  |
| BAR-Gs6 | Bar G#6 | 1 | 10.5 x 1.625 x 1.0 | 9.363 x 1.500 x 0.875 | longitudinal-quarter |  |
| BAR-A6 | Bar A6 | 1 | 10.0 x 1.625 x 1.0 | 9.097 x 1.500 x 0.875 | longitudinal-quarter |  |
| BAR-As6 | Bar A#6 | 1 | 9.5 x 1.625 x 1.0 | 8.838 x 1.500 x 0.875 | longitudinal-quarter |  |
| BAR-B6 | Bar B6 | 1 | 9.5 x 1.625 x 1.0 | 8.586 x 1.500 x 0.875 | longitudinal-quarter |  |
| BAR-C7 | Bar C7 | 1 | 9.0 x 1.625 x 1.0 | 8.342 x 1.500 x 0.875 | longitudinal-quarter |  |
| RAIL-L | Suspension rail left | 1 | 22.0 x 2.5 x 1.5 | 21.000 x 2.250 x 1.250 | longitudinal | both rails identical |
| RAIL-R | Suspension rail right | 1 | 22.0 x 2.5 x 1.5 | 21.000 x 2.250 x 1.250 | longitudinal |  |
| LEG-FL | Front-left leg | 1 | 32.0 x 1.75 x 1.75 | 30.000 x 1.500 x 1.500 | longitudinal | chamfer top edge for cord clearance |
| LEG-FR | Front-right leg | 1 | 32.0 x 1.75 x 1.75 | 30.000 x 1.500 x 1.500 | longitudinal |  |
| LEG-RL | Rear-left leg | 1 | 32.0 x 1.75 x 1.75 | 30.000 x 1.500 x 1.500 | longitudinal |  |
| LEG-RR | Rear-right leg | 1 | 32.0 x 1.75 x 1.75 | 30.000 x 1.500 x 1.500 | longitudinal |  |
| GUSSET | Corner gusset | 4 | 7.0 x 7.0 x 0.5 | 6.000 x 6.000 x 0.500 | plywood-9-ply | 45-degree triangle gussets at leg-to-rail joint |

## drawing-brief.md

Manufacturing drawing and technical product sketch brief.

# Xylophone — Drawing Brief

What the SVG and CAD drawings need to show, in priority order. The
drawings live in `drawings/` (per-family-member SVGs and a frame
elevation/plan); the CAD master lives in `cad/` once built.

## DR-01: Bar template (parametric)

A single dimensioned drawing template that varies per family member.
**Critical dimensions:**

- Bar length `L` (from `family-spec.csv` per note).
- Bar width `W = 1.500"`.
- Bar thickness `h = 0.875"` (section view).
- Node-hole positions: low-side at `0.224 × L`, high-side at
  `0.776 × L`. Hole diameter `1/8"`.
- Strike line at center (`L/2`) — annotation only, not a feature.
- Edge round-over `1/16"` on all four long edges.

Title block must show: drawing ID, note name, family `XYL`, scale
(1:2 reads cleanly for the long bars), revision, date, designer,
material, finish.

The drawing template's only variable is `L` and the two derived hole
positions. A generator should be able to produce 25 SVGs from the
family table by string substitution alone.

## DR-02: Frame elevation

Side view of the assembled frame (no bars). Shows:

- Two suspension rails, `21.000" × 2.250" × 1.250"`, mounted on top
  of the legs.
- Four legs, `30.000" × 1.500" × 1.500"`. Chamfered top edge.
- Corner gussets, `6.000 × 6.000 × 0.500"` plywood, on the inside
  face of each leg-rail joint.
- Cord-suspension geometry — schematic, not dimensioned.
- Overall envelope: 21" wide, 30" tall.

## DR-03: Frame plan

Top view of the frame with bars laid in suspension. Shows:

- Both rails parallel, 6.5" inside-to-inside.
- 25 bar positions in the family-table order, lowest at the left.
- Inter-bar gap: 0.250" minimum.
- Total bar-array length: ~17" (driven by the longest bar plus
  gaps).
- Cord routing: alternating side-to-side through node holes.

## DR-04: Mallet detail

Three-view of the recommended hard-rubber mallet (from `bom.csv`).
Shaft length, head diameter, head shape. **Reference only** — the
mallets are purchased, not built. Goes on the visual BOM, not in
the build instructions.

## Style notes

- All dimensions in inches. Decimal, three places (`16.683`),
  consistent with `family-spec.csv` and `cut-list.csv`.
- Datum chain: bar drawings reference left bar end; frame drawings
  reference left-rear leg base.
- Tolerances: bars ±1/64", frame ±1/32" (frame loose on purpose —
  bars do the precision work).
- File names: `drawings/DR-01-bar-<note>.svg` per bar (or a single
  `drawings/template.svg` until the per-bar instances are
  generated). Frame drawings: `drawings/DR-02-frame-elevation.svg`,
  `drawings/DR-03-frame-plan.svg`. Mallet: `drawings/DR-04-mallet.svg`.

## Generator hookup

A future invocation of `scripts/generate_drawings.py` against this
packet will populate `drawings/DR-01-bar-*.svg` from `family-spec.csv`.
Until that runs, `drawings/template.svg` is the placeholder showing
the title-block layout and the datum chain so the generator's output
matches in style.

## assembly-manual.md

Shop-facing sequence, tools, fixtures, safety, tuning, finishing, and maintenance notes.

# Xylophone — Assembly Manual

14 shop steps, in order. Checkboxes are blank for shop use; tick them
off as you go. Estimated total bench time: **3 working days** with
overnight glue cures.

## Materials and tools required

Read `bom.csv` and `sourcing.csv` end-to-end before starting. The
critical-path items: Padauk bar stock at 6–8% MC, Korg OT-120 tuner,
1/8" brad-point bit, Titebond III, tung oil, and the two jigs from
`jig-decision.md` (node-hole drilling jig, end-shaving sled).

## Step 1 — Verify moisture content

- [ ] Pin-meter the Padauk bar stock at three points along each
  board. Target 6.0–8.0% MC.
- [ ] Log temp + RH in the shop in `validation.csv` row V1.
- [ ] If MC > 8%: stack with stickers in the shop for two weeks and
  remeasure. **Do not proceed until MC is 6–8%.**

## Step 2 — Mill blanks to rough cut-list dimensions

- [ ] Cross-cut each bar blank to its `rough_dimensions_in[0]` length
  (per `cut-list.csv`). Add 1" to the longest blanks for safety.
- [ ] Rip to 1.625" rough width.
- [ ] Joint one face and one edge.
- [ ] Plane to 1.0" rough thickness.

## Step 3 — Final mill bars

- [ ] Plane to **0.875"** final thickness.
- [ ] Rip to **1.500"** final width.
- [ ] Cross-cut to the `final_dimensions_in[0]` length per
  `cut-list.csv`. **Cut long by 1/16"** — final length is set in
  the tuning step.

## Step 4 — Surface prep

- [ ] Drum-sand or hand-sand each bar 80 → 120 → 180 → 220.
- [ ] Ease all four long edges with a 1/16" round-over.
- [ ] Mark each bar's note name on the underside in pencil.

## Step 5 — Drill node holes (jig)

- [ ] Set up the node-hole drilling jig from `jig-decision.md`.
- [ ] For each bar: set both flip-stops to the bar's
  `hole_pos_low_in` and `hole_pos_high_in` from `family-spec.csv`.
- [ ] Drill the low-side hole, flip stops, drill the high-side hole.
- [ ] Chamfer both holes ~0.5mm with a countersink to prevent cord
  chafing.

## Step 6 — First measurement

- [ ] Suspend each bar from a piece of test-cord through both node
  holes.
- [ ] Strike with the hard rubber mallet, measure with the Korg
  OT-120.
- [ ] Log result for each bar in `validation.csv` row V2.
- [ ] **Expected outcome:** bars read 5–25 cents *low* of target.
  This is normal — final length is shaved in the next step.

## Step 7 — Tune by end-shaving

- [ ] On the end-shaving sled: shave equal amounts from each bar end
  in 1/64" increments. Symmetric shaving keeps the node positions
  centered.
- [ ] After each pass, re-suspend, re-strike, re-measure. Stop when
  cents-actual is within ±2 cents of target.
- [ ] Log result in `validation.csv` row V3.
- [ ] If a bar overshoots (reads sharp): **do not add material**.
  Either accept the +cents or scrap the bar.

## Step 8 — Mill frame parts

- [ ] Mill the two suspension rails to `21.000 × 2.250 × 1.250"`.
- [ ] Mill four legs to `30.000 × 1.500 × 1.500"`. Chamfer the top
  edge of each leg to clear the suspension cord.
- [ ] Cut four corner gussets from 1/2" Baltic birch plywood at
  `6.000 × 6.000"`, hypotenuse to hypotenuse (i.e., 45-degree
  triangles).

## Step 9 — Frame dry-fit

- [ ] Dry-assemble the frame: legs into rails via the gussets.
- [ ] Verify rail-to-rail spacing is 6.5" inside-to-inside (matches
  the bar width plus suspension margin).
- [ ] Verify legs are square to rails.

## Step 10 — Frame glue-up

- [ ] Apply Titebond III to all gusset-to-frame joints.
- [ ] Drive #10 × 2" wood screws through pilot holes (Padauk and
  hard maple both want pilots).
- [ ] Clamp 24 hours. Do not flex the frame during cure.

## Step 11 — Apply finish

- [ ] Wipe each bar with mineral spirits to remove sanding dust.
- [ ] Apply pure tung oil with a lint-free rag, three coats. Each
  coat dries 24 hours; sand lightly between coats with 320.
- [ ] Apply finish to the frame the same way (two coats is enough).
- [ ] **24 hours after the last bar coat:** re-measure each bar.
  Log in `validation.csv` row V4. Expected drift: −2 to −4 cents
  from finish mass loading. If drift exceeds −5 cents, end-shave
  again to compensate.

## Step 12 — Top-coat and cure

- [ ] Apply beeswax paste over the cured tung oil; buff out.
- [ ] Allow seven days at shop ambient before play-testing.

## Step 13 — Suspend bars

- [ ] Cut paracord to length: rail length × 2 + 12" tail per rail.
- [ ] Tie a stopper knot at each rail end.
- [ ] Thread cord through node holes in C5–C7 order, alternating
  bar-to-cord-to-bar.
- [ ] Terminate at the second rail with brass finish washers and a
  tied loop.

## Step 14 — Final validation

- [ ] Photograph the finished assembly per `photo-shotlist.md`
  shots 1, 2, 4, 5, 6, 7, 10.
- [ ] Run validation row V8 (full-octave evenness): measure C5, C6,
  C7 in one session. Document spread.
- [ ] Schedule validation rows V6 (30-day) and V7 (60-day) on the
  shop calendar.
- [ ] Mark this packet as `built` in the master catalog.

## validation.csv

Target/measured values, tolerance, environment, result, and tuning/build action log.

| row_id | note_id | phase | target_hz | measured_hz | cents_target | cents_actual | tuner_make_model | temp_F | humidity_RH_percent | environment_notes | date | result |
| --- | --- | --- | --- | --- | --- | --- | --- | --- | --- | --- | --- | --- |
| V1 | ALL | prediction-paper | per family-spec |  | 0 |  | N/A | 68 | 45 | design table, pre-cut |  | first-order Euler-Bernoulli prediction; logged from family-spec.csv |
| V2 | A5 | post-cut | 880.00 |  | 0 |  | Korg OT-120 | 68 | 45 | shop bench, immediately after surface plane |  | first measurement; expected to read low if length over rough |
| V3 | A5 | post-shave | 880.00 |  | 0 |  | Korg OT-120 | 68 | 45 | shop bench, after end-shaving for fundamental |  | shave 1/64 in increments; recheck |
| V4 | A5 | post-finish | 880.00 |  | -3 to 0 |  | Korg OT-120 | 68 | 45 | shop bench, 24 hours after final tung-oil coat |  | finish adds mass; expected drift -2 to -4 cents |
| V5 | A5 | post-resonator-install | 880.00 |  | 0 |  | Korg OT-120 | 68 | 45 | shop, with resonator tube installed at quarter-wave length |  | deferred to v2 build |
| V6 | ALL | 30-day-moisture | per family-spec |  | within +/-5 |  | Korg OT-120 | TBD | TBD | 30 days post-finish; log temp and RH |  | retune any bar drifting beyond +/-5 cents |
| V7 | ALL | 60-day-moisture | per family-spec |  | within +/-5 |  | Korg OT-120 | TBD | TBD | 60 days post-finish; log temp and RH |  | second moisture check; if stable retire moisture rows |
| V8 | C5-C6-C7 | full-octave-evenness | 523.25, 1046.50, 2093.00 |  | within +/-5 across the three Cs |  | Korg OT-120 | 68 | 45 | all three Cs measured in one session for evenness |  | if greater than 10 cents spread, escalate to design review |

## supplier-rfq.md

Supplier email/request-for-quote starter.

# Xylophone — Supplier RFQ

Template — paste into supplier email or web form. The bar-stock RFQ
is the only critical-path RFQ; everything else is COTS from
`sourcing.csv` and does not need a custom quote.

---

**Subject:** Padauk bar-stock quote — 25-bar xylophone build

Hello,

I'm building a 25-bar chromatic xylophone (C5–C7) and I'd like a
quote on Padauk lumber for the bar set. Specs:

- **Species:** African Padauk (*Pterocarpus soyauxii*) — *not*
  Burma Padauk.
- **Form:** 4/4 lumber (15/16" rough, surfaced 4 sides to roughly
  3/4"–7/8" final), or fall-back to S2S if S4S is unavailable.
- **Grain:** **Quartersawn** strongly preferred (radial grain on the
  bar face). Riftsawn acceptable on 25–35% of the order. Flatsawn
  rejected — bars will warp.
- **Moisture content:** **Kiln-dried to 6–8% MC.** Please measure with
  a pin meter at multiple points and confirm in writing.
- **Defect tolerance:** No knots, no shake, no end-checks longer than
  1/2", no insect damage, no sap pockets. Color variation acceptable.
- **Total board feet:** Approximately **15 BF** to yield 25 bars
  (longest 17", shortest 9", at 1.5"×7/8") plus 20% waste.
- **Lengths preferred:** Boards in the 36–48" range. Anything shorter
  than 24" is hard to use.

Please quote:

1. Per-board-foot price for the spec above.
2. Total for 15 BF, FOB your shipping point.
3. Lead time from order to ship.
4. Photographs of two or three representative boards before payment
   so I can confirm grain orientation and color.

If S4S quartersawn is not available at this volume, please quote for
S2S quartersawn at 5/4 thickness instead and I'll mill to 7/8" myself.

Thanks,
Tony Koop
tonykoop@gmail.com

---

## RFQ tracking

| Field | Value |
|---|---|
| RFQ ID | XYL-RFQ-001 |
| Spec sheet | `bom.csv` row `BAR-STOCK` |
| Sourcing options  | `sourcing.csv` rows for `BAR-STOCK` |
| Sent date | TBD |
| Quote received | TBD |
| Decision | TBD |
| Order placed | TBD |
| Received in shop  | TBD |
| MC at receipt | TBD (target 6–8%; measure on arrival) |

## Decision criteria

Pick the supplier whose quote yields **best (price × delivery × grade
match)**. Bell Forest Products is the default expectation; West Penn
and Cook are the named backups in `sourcing.csv`.

## What to do if no supplier can deliver to spec

Fall-back order: switch the spec's primary species in
`xylophone-design-table.xlsx` from Padauk to Hard Maple (Tier 3 in
`design.md`). Re-run the family table — predicted lengths shift
slightly because Maple's √(E/ρ) is 4229 m/s vs Padauk's 4112. Bars
end up about 1.4% longer. Update `family-spec.csv` and `cut-list.csv`
accordingly.

## visual-bom-brief.md

Art direction for an image-forward visual BOM.

# Xylophone — Visual BOM Brief

Brief for the visual BOM (the recruiter-facing assembly plate). One
page, every line in `bom.csv` represented by a thumbnail and a
two-line label.

## Page layout

- **Header.** Project name + version + quote date + total cost.
- **Hero strip** at top: `images/01-hero.jpg` (or the placeholder
  SVG until captured), full-width.
- **Three columns** of part rows below the hero, top-to-bottom:
  bar stock + finishing on the left, frame stock + hardware in the
  middle, mallets + tuning + measurement gear on the right.
- **Footer.** Total cost, link to the GitHub repo, license note.

## Part-row anatomy

Each row:

```
[thumbnail 60×60]  PART_ID — Part Name
                   Qty • Unit • Estimated cost • Supplier
                   One-line spec summary
```

Thumbnails are pulled from `images/` by part-id slug. When an image
is missing, fall back to a category placeholder (a square with the
part-id text centered, no decoration).

## Mapping bom.csv → visual BOM

| bom.csv part_id | Image slug | Notes for plate |
|---|---|---|
| BAR-STOCK | `images/02-bar-fan.jpg` | top-left, biggest cell |
| FRAME-RAIL | `images/04-frame-elevation.jpg` | use frame photo cropped to rails |
| FRAME-LEG | `images/04-frame-elevation.jpg` | crop to legs |
| FRAME-GUSSET | placeholder square | small detail, use category placeholder |
| CORD-NODE | `images/06-suspension-cord.jpg` | cord visible against bars |
| CORD-WASHER | placeholder square | |
| SCREW-FRAME | placeholder square | |
| GLUE-FRAME | placeholder square | |
| FINISH-OIL | placeholder square | |
| FINISH-WAX | placeholder square | |
| MALLET-HRD | `images/05-mallet-trio.jpg` | crop to hard-rubber mallet |
| MALLET-MED | `images/05-mallet-trio.jpg` | crop to medium yarn mallet |
| TUNER-CHROMA | `images/07-tuner-on-bar.jpg` | OT-120 mid-measurement |
| HYGRO-SHOP | placeholder square | |
| MOIST-METER | `images/09-moisture-meter.jpg` | meter on Padauk end-grain |
| SANDPAPER-KIT | placeholder square | |
| DRILL-BIT-NODE | placeholder square | |
| RESONATOR-TUBE | placeholder square — deferred | grey out the row; v2 build |

## Style

- Black text on white background. No decorative shading.
- Font: Inter or system-ui. Body 9pt, headings 11pt, totals 13pt.
- Print target: US Letter portrait, 0.5" margins. The visual BOM is
  the one page that must be printable in a shop.

## Output

The visual BOM is rendered as part of the print packet
(`print-packet.html` and `print-packet.pdf`). The HTML is the
source of truth; the PDF is generated from it. When optional PDF
deps are missing, the HTML alone is shippable.

## wolfram-starter.wl

Wolfram starter for physics, optimization, visualization, and validation.

```wolfram
(* ::Package:: *)

(* Xylophone — instrument-model.wl                                          *)
(* Free-free Euler-Bernoulli flat-bar idiophone. First-mode prediction,     *)
(* node positions, optional quarter-wave closed-pipe resonator, validation  *)
(* plot scaffolding, audio preview.                                         *)
(*                                                                          *)
(* Read references/wolfram-workflow.md before extending this file.          *)

(* ::Section:: *)
(* Parameters *)

(* Wood species shortlist — Padauk is the spec primary. Override by editing. *)
woodPadauk = <| "name" -> "African Padauk", "EGPa" -> 12.6, "rhoKg" -> 745. |>;
woodHondurasRosewood = <| "name" -> "Honduras Rosewood", "EGPa" -> 14.1, "rhoKg" -> 1000. |>;
woodHardMaple = <| "name" -> "Hard Maple", "EGPa" -> 12.6, "rhoKg" -> 705. |>;

(* Active wood — the only switch that matters at the top of the file. *)
woodActive = woodPadauk;

(* Bar geometry constants (held constant within a family in v1). *)
barWidthIn = 1.5;
barThickIn = 0.875;
inToM = 0.0254;

(* Resonator geometry. *)
resonatorBoreIn = 1.5;
soundSpeedAir = 343.0;            (* m/s at ~20 C *)
endCorrectionFactor = 0.82;        (* per acoustic-models.md, quarter-wave closed pipe *)

(* ::Section:: *)
(* Governing model *)

(* Free-free Euler-Bernoulli first mode:
       f1 = 1.028 * (h / L^2) * Sqrt[E/rho]
   Reference: acoustic-models.md, Free-Free Beams section.
   First-order only — K2 and end-corrections do not apply to bar idiophones. *)

soundSpeedSolid[E_, rho_] := Sqrt[(E*10.^9) / rho];

f1FromGeometry[L_, h_, E_, rho_] :=
  1.028 * (h / L^2) * soundSpeedSolid[E, rho];

lengthFromTarget[fTarget_, h_, E_, rho_] :=
  Sqrt[1.028 * h * soundSpeedSolid[E, rho] / fTarget];

resonatorLength[fTarget_, boreIn_] := Module[{boreM, lM},
  boreM = boreIn * inToM;
  lM = soundSpeedAir / (4 * fTarget) - endCorrectionFactor * boreM;
  lM / inToM
];

(* ::Section:: *)
(* Family table generation *)

chromaticC5toC7Notes = {
  {"C5",523.25},{"C#5",554.37},{"D5",587.33},{"D#5",622.25},
  {"E5",659.26},{"F5",698.46},{"F#5",739.99},{"G5",783.99},
  {"G#5",830.61},{"A5",880.00},{"A#5",932.33},{"B5",987.77},
  {"C6",1046.50},{"C#6",1108.73},{"D6",1174.66},{"D#6",1244.51},
  {"E6",1318.51},{"F6",1396.91},{"F#6",1479.98},{"G6",1567.98},
  {"G#6",1661.22},{"A6",1760.00},{"A#6",1864.66},{"B6",1975.53},
  {"C7",2093.00}
};

familyRow[note_String, fHz_?NumericQ] := Module[{Lm, Lin, holeLo, holeHi, Lres},
  Lm  = lengthFromTarget[fHz, barThickIn * inToM, woodActive["EGPa"], woodActive["rhoKg"]];
  Lin = Lm / inToM;
  holeLo = 0.224 * Lin;
  holeHi = 0.776 * Lin;
  Lres   = resonatorLength[fHz, resonatorBoreIn];
  <| "note" -> note, "fHz" -> fHz, "LIn" -> Lin,
     "holeLoIn" -> holeLo, "holeHiIn" -> holeHi,
     "resonatorLIn" -> Lres |>
];

familyTable := familyRow @@@ chromaticC5toC7Notes;

(* ::Section:: *)
(* Manipulate — interactive bar-length explorer *)

(* The Manipulate lets you sweep wood/L/h and see f1 in real time.
   Useful for sanity-checking first-order predictions and for showing
   players the why-bigger-is-lower-pitched relationship.            *)

manipulateBar := Manipulate[
  With[{
    fHz = f1FromGeometry[
      LIn * inToM, hIn * inToM, EChoice, rhoChoice]},
    Column[{
      Style[
        StringForm["f1 = `` Hz", NumberForm[fHz, {6, 2}]],
        Bold, 18],
      Plot[
        f1FromGeometry[L * inToM, hIn * inToM, EChoice, rhoChoice],
        {L, 4, 24}, AxesLabel -> {"L (in)", "f1 (Hz)"},
        PlotRange -> {0, 3000},
        GridLines -> {{LIn}, {fHz}}
      ]
    }]],
  {{LIn, 12.0, "bar length L (in)"}, 4.0, 24.0, 0.05},
  {{hIn, 0.875, "bar thickness h (in)"}, 0.5, 1.5, 0.01},
  {{EChoice, 12.6, "Young's modulus E (GPa)"}, 8.0, 16.0, 0.1},
  {{rhoChoice, 745.0, "density rho (kg/m^3)"}, 600.0, 1100.0, 5.0},
  ControlPlacement -> Top
];

(* ::Section:: *)
(* Audio preview *)

(* Synthesizes a 0.6-second pluck of the predicted fundamental for each
   note in the chromatic table. First-order only — not the actual modal
   spectrum of a real bar, just a confirmation of the predicted f1.   *)

audioForNote[fHz_?NumericQ] :=
  AudioPad[
    Sound[SoundNote[None, 0.0]] /. _ ->
      AudioGenerator["Sin", 0.6, "Frequency" -> fHz, SampleRate -> 44100],
    {0, 0.05}
  ];

playFamily := AudioJoin @@ (audioForNote[#[[2]]] & /@ chromaticC5toC7Notes);

(* ::Section:: *)
(* Validation plot scaffold *)

(* Compare predicted f1 (column 1) to measured Hz (column 2) once the
   shop log fills in. Until measurements exist, the plot just shows
   the predicted line and a residual band. Wire to validation.csv via
   record_measurement.py.                                              *)

predictedVsMeasuredPlot[predicted_List, measured_List] :=
  ListPlot[
    {predicted, measured},
    PlotStyle -> {{Thick, Blue}, {PointSize[0.012], Red}},
    PlotLegends -> {"predicted", "measured"},
    AxesLabel -> {"note index (low → high)", "f1 (Hz)"},
    PlotRange -> All,
    GridLines -> Automatic
  ];

centsErrorPlot[predicted_List, measured_List] :=
  ListPlot[
    1200. * Log[2., measured / predicted],
    Filling -> Axis,
    PlotRange -> {-30, 30},
    AxesLabel -> {"note index", "cents error (measured − predicted)"},
    GridLines -> {None, {-5, 0, 5}}
  ];

(* ::Section:: *)
(* Document entry point *)

(* CreateDocument call lives in the notebook layer, not here. Open this
   .wl in Wolfram Desktop, evaluate manipulateBar, then evaluate
   playFamily to hear the predicted family.                             *)

(* End of file *)
```

## README.md

Project artifact.

# Xylophone

Xylophone hero — 25-bar chromatic in Padauk on a parametric trestle frame (placeholder)

A 25-bar chromatic xylophone, **C5 to C7**, in African Padauk on a
parametric trestle frame. Free-free flat-bar geometry, 12th-overtone
tuning convention, optional quarter-wave closed-pipe resonators
(deferred to v2). This repo is a v4.3 root-mode build packet from the
[`tonykoop/instrument-maker`](https://github.com/tonykoop/instrument-maker)
catalogue, designed deliberately as the *simpler sibling* of a future
`tonykoop/marimba` repo.

## Background

The xylophone is the higher-pitched cousin of the marimba: same
physics (free-free Euler-Bernoulli transverse beam vibration), harder
mallets, shorter bars, and a different second-mode tuning convention.
This packet ships the bar physics, the wood-species shortlist, the
suspension geometry, the validation workflow, and the build process
end-to-end. It deliberately *defers* the things that make a marimba
hard — the parabolic arch undercut, the mandatory tuned resonators,
the multi-octave frame — so the xylophone build is feasible in one
shop session and so the marimba follow-on can inherit a clean
scaffold rather than starting from scratch.

The root-of-truth design table is `xylophone-design-table.xlsx` at
the repo root. Every length, hole position, and resonator length in
`family-spec.csv` is solved from the parametric inputs there.

## Design overview

- **Family:** 25 bars, C5 (523.25 Hz) through C7 (2093.00 Hz), chromatic.
- **Bar geometry:** flat-bottom rectangular, **1.500" × 0.875" cross
  section** held constant across the family. Length varies per note;
  see [`family-spec.csv`](family-spec.csv).
- **Wood:** **African Padauk** (sustainable, predictable acoustic
  properties, available in 4/4 quartersawn). Honduras Rosewood and
  Hard Maple are documented swap-ins.
- **Suspension:** 1/8" paracord through node holes drilled at 22.4%
  and 77.6% of bar length — the first free-free mode's nodes.
- **Tuning:** 12th-overtone convention noted as a *measurement
  target* on the validation sheet, not a CAD geometry. End-shaving
  is the production tuning method (no arch undercut — that's marimba).
- **Frame:** parametric 4-leg trestle, 21" wide × 30" tall, hard
  maple rails and legs with Baltic-birch corner gussets.
- **Resonators:** computed but optional. The L-per-note math is in
  `family-spec.csv` so adding resonators in v2 is additive.

## Family-table preview (first and last)

| Note | Target Hz | Bar L (in) | Hole low (in) | Hole high (in) | Resonator L (in) | Mass (oz) |
|---|---|---|---|---|---|---|
| C5 | 523.25 | 16.683 | 3.737 | 12.946 | 5.22 | 9.43 |
| A4 * | 440.00 | n/a | n/a | n/a | n/a | n/a |
| A5 | 880.00 | 12.865 | 2.882 | 9.983 | 2.61 | 7.27 |
| C7 | 2093.00 | 8.342 | 1.869 | 6.473 | 0.38 | 4.71 |

\* A4 = 440 Hz is the standard tuning reference; the family ranges
from C5 upward, so A4 itself is not a member.

Full table: [`family-spec.csv`](family-spec.csv).

## Why this packet exists

This is the v4.3 challenge run for the
[`instrument-maker-v4`](https://github.com/tonykoop/instrument-maker)
skill, exercising the **root-mode** packet contract end-to-end on a
new wooden-idiophone family. Specifically:

1. Validates the v4.3 root-mode validator (`validate_packet.py
   --mode root`) against a fresh Mode A repo.
2. Demonstrates the bar-idiophone branch of `acoustic-models.md`'s
   Free-Free Beams section with first-order honesty about K2 and
   end-correction guard rules.
3. Builds the design template that the marimba sister repo will
   inherit — every "marimba-equivalent: …" callout in
   [`design.md`](design.md) is a hook for the marimba build.

## Sister repos and references

- [`tonykoop/instrument-maker`](https://github.com/tonykoop/instrument-maker)
  — parent catalogue, the v4 skill source, references and scripts.
- [`tonykoop/tongue-drum`](https://github.com/tonykoop/tongue-drum) —
  closest sister repo: another wooden idiophone, free-free / cantilever
  beam math, SolidWorks master-layout convention, magazine-baseline
  attribution. The xylophone README borrows its structure.
- `tonykoop/marimba` *(planned)* — the natural follow-on; this
  packet's `design.md` calls out exactly what each marimba decision
  has to swap in (`Marimba-Equivalent Hooks` table).

## Repo layout

```
xylophone/
├── README.md                     ← this file
├── design.md                     ← governing model, family plan, decisions
├── family-spec.csv               ← parametric per-note table (25 rows)
├── bom.csv, sourcing.csv         ← parts and supplier candidates
├── cut-list.csv                  ← shop cut list (bars + frame)
├── validation.csv                ← measured-tuning workflow (8 rows)
├── assembly-manual.md            ← 14-step shop manual
├── supplier-rfq.md               ← bar-stock RFQ template
├── drawing-brief.md              ← what the SVG drawings must show
├── visual-bom-brief.md           ← printable visual BOM brief
├── wolfram-starter.wl            ← parametric Wolfram source
├── risks.md                      ← red-team risk register
├── resources.md                  ← citations and references
├── jig-decision.md               ← three jig build/no-build calls
├── photo-shotlist.md             ← ten-shot photo plan
├── capstone-deck.md / .pptx      ← recruiter-facing slide deck
├── print-packet.md / .html / .pdf ← shop-printable packet
├── capstone-manifest.json        ← deck-and-packet manifest
├── xylophone-design-table.xlsx   ← parametric source of truth
├── images/                       ← hero, build photos
├── drawings/                     ← per-bar SVGs + frame elevation/plan
├── cad/                          ← SolidWorks master (deferred)
├── cnc/                          ← cnc-plan.json + setup-sheet.md
├── jigs/                         ← jig sketches (deferred)
└── site/                         ← static build-log site
```

## License

[CC BY 4.0](LICENSE) — see LICENSE for details.

## family-spec.csv

Project artifact.

| note | target_hz | bar_length_in | bar_width_in | bar_thickness_in | hole_pos_low_in | hole_pos_high_in | predicted_f1_hz | predicted_f1_source | wood_species | resonator_l_in_optional | mass_oz_est | notes |
| --- | --- | --- | --- | --- | --- | --- | --- | --- | --- | --- | --- | --- |
| C5 | 523.25 | 16.683 | 1.500 | 0.875 | 3.737 | 12.946 | 523.25 | free-free Euler-Bernoulli f1=1.028(h/L^2)sqrt(E/rho); first-order; Padauk E=12.6GPa rho=745kg/m3 | Padauk | 5.22 | 9.43 | solved L from target_hz |
| C#5 | 554.37 | 16.208 | 1.500 | 0.875 | 3.631 | 12.578 | 554.37 | free-free Euler-Bernoulli f1=1.028(h/L^2)sqrt(E/rho); first-order; Padauk E=12.6GPa rho=745kg/m3 | Padauk | 4.86 | 9.16 | solved L from target_hz |
| D5 | 587.33 | 15.747 | 1.500 | 0.875 | 3.527 | 12.220 | 587.33 | free-free Euler-Bernoulli f1=1.028(h/L^2)sqrt(E/rho); first-order; Padauk E=12.6GPa rho=745kg/m3 | Padauk | 4.52 | 8.90 | solved L from target_hz |
| D#5 | 622.25 | 15.299 | 1.500 | 0.875 | 3.427 | 11.872 | 622.25 | free-free Euler-Bernoulli f1=1.028(h/L^2)sqrt(E/rho); first-order; Padauk E=12.6GPa rho=745kg/m3 | Padauk | 4.20 | 8.65 | solved L from target_hz |
| E5 | 659.26 | 14.863 | 1.500 | 0.875 | 3.329 | 11.534 | 659.26 | free-free Euler-Bernoulli f1=1.028(h/L^2)sqrt(E/rho); first-order; Padauk E=12.6GPa rho=745kg/m3 | Padauk | 3.89 | 8.40 | solved L from target_hz |
| F5 | 698.46 | 14.440 | 1.500 | 0.875 | 3.235 | 11.205 | 698.46 | free-free Euler-Bernoulli f1=1.028(h/L^2)sqrt(E/rho); first-order; Padauk E=12.6GPa rho=745kg/m3 | Padauk | 3.60 | 8.16 | solved L from target_hz |
| F#5 | 739.99 | 14.029 | 1.500 | 0.875 | 3.142 | 10.886 | 739.99 | free-free Euler-Bernoulli f1=1.028(h/L^2)sqrt(E/rho); first-order; Padauk E=12.6GPa rho=745kg/m3 | Padauk | 3.33 | 7.93 | solved L from target_hz |
| G5 | 783.99 | 13.630 | 1.500 | 0.875 | 3.053 | 10.577 | 783.99 | free-free Euler-Bernoulli f1=1.028(h/L^2)sqrt(E/rho); first-order; Padauk E=12.6GPa rho=745kg/m3 | Padauk | 3.08 | 7.70 | solved L from target_hz |
| G#5 | 830.61 | 13.242 | 1.500 | 0.875 | 2.966 | 10.275 | 830.61 | free-free Euler-Bernoulli f1=1.028(h/L^2)sqrt(E/rho); first-order; Padauk E=12.6GPa rho=745kg/m3 | Padauk | 2.83 | 7.48 | solved L from target_hz |
| A5 | 880.00 | 12.865 | 1.500 | 0.875 | 2.882 | 9.983 | 880.00 | free-free Euler-Bernoulli f1=1.028(h/L^2)sqrt(E/rho); first-order; Padauk E=12.6GPa rho=745kg/m3 | Padauk | 2.61 | 7.27 | solved L from target_hz |
| A#5 | 932.33 | 12.498 | 1.500 | 0.875 | 2.800 | 9.699 | 932.33 | free-free Euler-Bernoulli f1=1.028(h/L^2)sqrt(E/rho); first-order; Padauk E=12.6GPa rho=745kg/m3 | Padauk | 2.39 | 7.06 | solved L from target_hz |
| B5 | 987.77 | 12.143 | 1.500 | 0.875 | 2.720 | 9.423 | 987.77 | free-free Euler-Bernoulli f1=1.028(h/L^2)sqrt(E/rho); first-order; Padauk E=12.6GPa rho=745kg/m3 | Padauk | 2.19 | 6.86 | solved L from target_hz |
| C6 | 1046.50 | 11.797 | 1.500 | 0.875 | 2.643 | 9.154 | 1046.50 | free-free Euler-Bernoulli f1=1.028(h/L^2)sqrt(E/rho); first-order; Padauk E=12.6GPa rho=745kg/m3 | Padauk | 2.00 | 6.67 | solved L from target_hz |
| C#6 | 1108.73 | 11.461 | 1.500 | 0.875 | 2.567 | 8.894 | 1108.73 | free-free Euler-Bernoulli f1=1.028(h/L^2)sqrt(E/rho); first-order; Padauk E=12.6GPa rho=745kg/m3 | Padauk | 1.81 | 6.48 | solved L from target_hz |
| D6 | 1174.66 | 11.135 | 1.500 | 0.875 | 2.494 | 8.641 | 1174.66 | free-free Euler-Bernoulli f1=1.028(h/L^2)sqrt(E/rho); first-order; Padauk E=12.6GPa rho=745kg/m3 | Padauk | 1.64 | 6.29 | solved L from target_hz |
| D#6 | 1244.51 | 10.818 | 1.500 | 0.875 | 2.423 | 8.395 | 1244.51 | free-free Euler-Bernoulli f1=1.028(h/L^2)sqrt(E/rho); first-order; Padauk E=12.6GPa rho=745kg/m3 | Padauk | 1.48 | 6.11 | solved L from target_hz |
| E6 | 1318.51 | 10.510 | 1.500 | 0.875 | 2.354 | 8.156 | 1318.51 | free-free Euler-Bernoulli f1=1.028(h/L^2)sqrt(E/rho); first-order; Padauk E=12.6GPa rho=745kg/m3 | Padauk | 1.33 | 5.94 | solved L from target_hz |
| F6 | 1396.91 | 10.211 | 1.500 | 0.875 | 2.287 | 7.923 | 1396.91 | free-free Euler-Bernoulli f1=1.028(h/L^2)sqrt(E/rho); first-order; Padauk E=12.6GPa rho=745kg/m3 | Padauk | 1.19 | 5.77 | solved L from target_hz |
| F#6 | 1479.98 | 9.920 | 1.500 | 0.875 | 2.222 | 7.698 | 1479.98 | free-free Euler-Bernoulli f1=1.028(h/L^2)sqrt(E/rho); first-order; Padauk E=12.6GPa rho=745kg/m3 | Padauk | 1.05 | 5.61 | solved L from target_hz |
| G6 | 1567.98 | 9.638 | 1.500 | 0.875 | 2.159 | 7.479 | 1567.98 | free-free Euler-Bernoulli f1=1.028(h/L^2)sqrt(E/rho); first-order; Padauk E=12.6GPa rho=745kg/m3 | Padauk | 0.92 | 5.45 | solved L from target_hz |
| G#6 | 1661.22 | 9.363 | 1.500 | 0.875 | 2.097 | 7.266 | 1661.22 | free-free Euler-Bernoulli f1=1.028(h/L^2)sqrt(E/rho); first-order; Padauk E=12.6GPa rho=745kg/m3 | Padauk | 0.80 | 5.29 | solved L from target_hz |
| A6 | 1760.00 | 9.097 | 1.500 | 0.875 | 2.038 | 7.059 | 1760.00 | free-free Euler-Bernoulli f1=1.028(h/L^2)sqrt(E/rho); first-order; Padauk E=12.6GPa rho=745kg/m3 | Padauk | 0.69 | 5.14 | solved L from target_hz |
| A#6 | 1864.66 | 8.838 | 1.500 | 0.875 | 1.980 | 6.858 | 1864.66 | free-free Euler-Bernoulli f1=1.028(h/L^2)sqrt(E/rho); first-order; Padauk E=12.6GPa rho=745kg/m3 | Padauk | 0.58 | 5.00 | solved L from target_hz |
| B6 | 1975.53 | 8.586 | 1.500 | 0.875 | 1.923 | 6.663 | 1975.53 | free-free Euler-Bernoulli f1=1.028(h/L^2)sqrt(E/rho); first-order; Padauk E=12.6GPa rho=745kg/m3 | Padauk | 0.48 | 4.85 | solved L from target_hz |
| C7 | 2093.00 | 8.342 | 1.500 | 0.875 | 1.869 | 6.473 | 2093.00 | free-free Euler-Bernoulli f1=1.028(h/L^2)sqrt(E/rho); first-order; Padauk E=12.6GPa rho=745kg/m3 | Padauk | 0.38 | 4.71 | solved L from target_hz |

## jig-decision.md

Project artifact.

# Xylophone — Jig Decisions

Three jig decisions, each with build/no-build recommendation, the
break-even calculation that drives it, and a one-paragraph build
sketch when the answer is build.

## 1. Node-hole drilling jig — **BUILD**

**Decision.** Build a fixed-fence drilling jig with two adjustable
stops keyed to the 22.4% / 77.6% positions of the bar length.

**Rationale.** 25 bars × 2 holes = 50 holes. Each hole must land
within ±1/32" of the node position or the bar's first mode picks up
audible damping. Hand-marking 50 holes from a tape measure is
unreliable at this tolerance. A jig with two flip-stops set against
the bar end pays back the build time on bar #4 or #5.

**Sketch.** Plywood base 22"×6"×1/2", drill press fence along the
back edge, two T-track flip-stops in a pair of 6" T-tracks routed
flush. Each bar's two stop positions get pre-marked on a strip
sticker per note — operator slides the bar against the front stop
for the low-side hole, drills, flips the front stop down and the
back stop up, drills the high-side hole. The stops are positioned
from the bar's actual length, not a percent, so the operator never
does math at the drill press.

## 2. Bar-end-shaving sled — **BUILD**

**Decision.** Build a low-angle hand-plane shooting sled sized to
the longest bar.

**Rationale.** Tuning happens by removing material from the bar
ends — *not* the underside (xylophone has no arch). End-shaving
needs to be square to the bar's long axis and parallel to the
opposite end, otherwise the bar develops a wedge that affects both
the fundamental tuning and the cord-hole alignment. A shooting sled
makes both square and parallel automatic.

**Sketch.** Hardwood base 20"×6", 90° fence along one long edge,
a stop block at the right end and a clamp wedge at the left. The
bar slides against the fence; the plane runs along the base; the
stop block prevents over-running the cut. A piece of 220 paper
glued to the fence prevents skating. Build the fence dead-square
to the base — measure with a machinist square before glue-up.

## 3. Frame-rail miter sled — **NO BUILD; use existing miter saw**

**Decision.** Cut the rail-to-leg miters on the existing sliding
compound miter saw. No jig.

**Rationale.** Eight 45° miters total (four leg ends × two each).
A standard miter saw with a sharp 80T blade lands every miter at
±0.25° easily, and the joints are reinforced by gusset plates
anyway. Building a miter sled would cost a half-day and pay back
nothing for an 8-cut job.

**Note for marimba sister repo.** A multi-octave marimba has 60+
miter cuts in the resonator-tube wells alone. The marimba repo
should re-evaluate this decision and likely build a dedicated
sled.

## photo-shotlist.md

Project artifact.

# Xylophone — Photo Shotlist

Ten shots that the build-log site, capstone deck, and visual BOM all
draw from. Tied to the repo-level `docs/photo-pipeline.md` rules
(neutral background, 5500K key light, sensor at instrument plane,
no flash, JPEG + RAW). When a photo is captured, drop it under
`images/` with the slug filename listed below — the deck and site
templates will pick them up.

## 1. Hero — `images/01-hero.jpg`

Full instrument on a clean dark-grey background, three-quarter angle
from above-right, both mallets resting at the keyboard end of the
frame. Lens normal-to-wide (35–50mm full frame). This is the README
hero swap — until captured, `images/xylophone-hero-placeholder.svg`
stands in.

## 2. Bar fan — `images/02-bar-fan.jpg`

All 25 bars laid out flat on a white seamless, shortest-to-longest,
1/2" gap between each. Top-down. This image goes on the deck's
"Family Plan" slide.

## 3. Node-hole detail — `images/03-node-hole-detail.jpg`

Macro of the 1/8" node hole on the C5 bar with paracord threaded
through. Lens 100mm macro. Light raking from one side to bring out
the cord texture and the hole chamfer. Goes on the assembly-manual's
node-suspension step.

## 4. Frame elevation — `images/04-frame-elevation.jpg`

Side-on, eye-level, frame only (no bars), centered. Shot far enough
back to be free of perspective distortion (~85mm full frame).
Used in `drawing-brief.md` as the dimension reference photo.

## 5. Mallet trio — `images/05-mallet-trio.jpg`

Hard rubber, lexan, and rosewood-head mallets laid parallel on a
white seamless, heads aligned at the top. Top-down. Used in the
`bom.csv`-driven visual BOM.

## 6. Suspension cord — `images/06-suspension-cord.jpg`

Three-quarter view of one full bar suspended on the cord at both
node holes, with the cord ends terminating at the rail with the brass
finish washers. Shows the geometry without the rest of the bars in
frame. Used on the build-log site's "How the bars are suspended"
section.

## 7. Tuner on bar — `images/07-tuner-on-bar.jpg`

The Korg OT-120 displayed mid-measurement on the A5 bar, mallet just
having struck. Captures the validation workflow in one frame. Used
on the validation slide of the deck.

## 8. Resonator stub — `images/08-resonator-stub.jpg` (deferred)

A single quarter-wave aluminum tube cut to the C5 resonator length
(5.22"), held against the underside of the suspended C5 bar. Shot
when v2 build adds resonators. Until then, this slot stays blank.

## 9. Moisture meter — `images/09-moisture-meter.jpg`

Pin meter inserted into the end-grain of a Padauk blank pre-glue-up,
display showing 6.5–7.5% MC. Goes on the assembly-manual's
"Verify moisture" step.

## 10. Finished assembly — `images/10-finished-assembly.jpg`

Three-quarter wide-angle of the finished xylophone in a play-ready
position (mallets in player's hands, bars attached, frame on a
real floor). Eye-level standing. The "this thing works" portrait
that closes the build-log site.

## resources.md

Project artifact.

# Xylophone — Resources

Citations, references, and the source-of-truth pointers that this
packet relies on. Where the packet states a number, this file says
*where the number came from*.

## Acoustic physics

- **Fletcher, Neville H., and Thomas D. Rossing.** *The Physics of
  Musical Instruments,* 2nd ed., Springer, 1998. Chapter 19 (Bars,
  Plates, and Membranes) — the canonical free-free Euler-Bernoulli
  derivation. Equations 19.7–19.13 yield the `K_free_free / K_cantilever
  = (4.730/1.875)² ≈ 6.36` factor used throughout this packet.
- **Bork, Ingolf.** "Practical Tuning of Xylophone Bars and Resonators,"
  *Applied Acoustics* 46 (1995): 103–127. Source for the 12th-overtone
  tuning convention and the bar-end-shaving correction shape. Bork's
  measured-vs-flat-bar second-mode ratio (~2.756) is the basis for the
  `first-mode-vs-second-mode-misalignment` risk.
- **Suits, B. H.** "Basic Physics of Xylophone and Marimba Bars."
  *American Journal of Physics* 69(7) (2001): 743–750. Clean
  derivation of the arch-undercut math the marimba sister repo will
  inherit; **explicitly cited** here as the "deferred-to-marimba"
  reference.
- **`acoustic-models.md`** (instrument-maker-v4 skill,
  `references/acoustic-models.md`). Free-Free Beams section is the
  primary citation — it both consolidates the formula in Tony's house
  units (h, L, E, ρ) and carries the empirical-correction guard rules
  that govern when K-constants do and do not apply.

## Material constants

- **Wood Database** (Eric Meier, https://www.wood-database.com/). E
  and ρ values for African Padauk (E ≈ 12.6 GPa, ρ ≈ 745 kg/m³),
  Honduras Rosewood (E ≈ 14.1 GPa, ρ ≈ 1000 kg/m³), and Hard Maple
  (E ≈ 12.6 GPa, ρ ≈ 705 kg/m³). Cross-checked against the K-constant
  table in `acoustic-models.md`.

## Tuning workflow / measurement

- **`record_measurement.py`** (instrument-maker-v4 skill,
  `scripts/record_measurement.py`). Schema for `validation.csv` and
  the per-family corrections database. The `tuner_make_model`,
  `temp_F`, `humidity_RH_percent`, and `cents_target` columns in
  this packet's `validation.csv` map 1:1 to the script's CLI flags.
- **Korg OT-120** orchestral chromatic tuner. ±0.1 cent accuracy in
  the C5–C7 range. Listed as the device of record in `bom.csv`.

## Empirical-correction guard rules

- **`acoustic-models.md`** "Empirical-correction guard rules" section.
  Cited in `design.md`'s Governing Model and in every prediction line
  of `family-spec.csv`. The summary in shop-friendly terms: K2 and
  end-corrections **do not apply** to bar idiophones; cantilever
  K-constants apply to free-free via the 6.36× factor; everything is
  *first-order* until measured.

## Repository conventions

- **`tongue-drum/README.md`** (sister repo). README structure,
  cross-repo link block, magazine-baseline attribution pattern. This
  packet's `README.md` rewrites in the same shape.
- **`tongue-drum/cad/`** (sister repo). SolidWorks master-layout
  convention for parametric design tables. Cited in `cad/README.md`
  as the model the xylophone CAD will follow when built.
- **`golden-examples.md`** (instrument-maker-v4 skill,
  `references/golden-examples.md`). Mode A root-mode layout exemplar
  — every file in this packet sits at the repo root because that
  reference says so.

## Marimba/xylophone difference summary

The single best one-page summary of how xylophone and marimba differ:
**Suits 2001** (above). The salient points the packet operationalizes:

- Xylophone tunes the second mode to a 12th (3:1 ratio) above the
  fundamental; marimba tunes to two octaves (4:1).
- Xylophone bars are typically rosewood or padauk, smaller cross-section,
  often without arch undercut in low-end / educational instruments.
- Xylophone resonators (when present) are shorter quarter-wave tubes;
  marimba resonators are tuned at the bench by ear.
- Mallets are harder for xylophone; bars consequently must be harder
  wood and well-supported at the nodes.

Every "marimba-equivalent" callout in `design.md` traces back to this
section.

## risks.md

Project artifact.

# Xylophone — Risks Register

Five categories, at least one entry each, every entry with an
attached verification *test* per the v4 red-team specialist contract.

## Acoustic

### bar-cracking-from-hard-mallets
**Risk.** Hard rubber and lexan mallets, especially struck near the
bar end rather than at the strike line, can crack a flat-bar Padauk
bar within months. Hard mallets are appropriate for xylophone — but
the failure mode is real and accelerates with low ambient humidity.

**Test.** Strike test: with the C5 bar (longest, most stress) clamped
in the suspension cord, strike 100 times near the strike line and
50 times deliberately near the end with a hard rubber mallet. Inspect
for hairline cracks under raking light. Repeat after 30 days at
shop ambient. Pass = no visible cracks; fail = any crack.

### first-mode-vs-second-mode-misalignment
**Risk.** First-order math predicts only `f_1`. The 12th-overtone
xylophone tuning convention asks for the second flexural mode to
sit at a 3:1 ratio, which a flat bar does **not** naturally do —
the unpinched second-mode ratio of a free-free Euler-Bernoulli
beam is closer to 2.756. Means players will hear the second mode
"out of tune" with the fundamental.

**Test.** Spectrum-analyzer measurement (free phone app like
SpectroidPro): pluck/strike the bar, capture the spectrum, identify
the fundamental and the strongest second peak, compute the ratio.
Pass = ratio between 2.7 and 3.0 (unundercut bars cluster around
2.756); fail = ratio outside that band. Document. The marimba sister
repo will fix this with arch undercut; the xylophone v1 packet
*accepts* the natural ratio and notes it on the validation sheet.

## Structural

### moisture-retune-drift
**Risk.** Padauk at 6–8% MC at glue-up will move when the shop ambient
changes. A 4% MC swing across a humid summer to a dry winter can shift
fundamentals by 5–15 cents. Not a structural failure, but a tuning
failure that compounds across all 25 bars.

**Test.** Record temp/RH at every measurement row in `validation.csv`
(rows V2 through V8). Re-measure every bar at 30 and 60 days
(rows V6, V7). Pass = drift within ±5 cents on all bars at both
checkpoints; fail = drift exceeds ±5 cents — flag the bar in
`record_measurement.py`, update the per-family corrections database.

### cord-hole-tear-out
**Risk.** 1/8" node holes drilled near the bar's high-stress mode
zone. Repeated player force on the cord at the hole can tear out the
hole, especially if grain runs across it.

**Test.** Pull-test on the longest bar (C5): tie the suspension cord
through both holes, suspend the bar, hang a 5-lb weight from the
center of the bar, hold for 60 seconds. Inspect holes for cracking
or elongation. Pass = no visible damage; fail = elongation, splitting,
or cord chafing. If fail, drill a slightly larger hole and chamfer
both ends.

## Ergonomic

### frame-tipping-on-uneven-floor
**Risk.** 4-leg trestle frame with a 21" rail and 30" leg height can
tip if a player strikes near the rail end with a heavy two-handed
attack on an uneven floor.

**Test.** Place frame on a 5° tilted board. Have a player strike
the C5 bar (rail end) with full two-handed force using yarn-wrapped
medium mallets. Frame should not tip. Pass = stable; fail = tips.
Mitigation if fail: add 6" leg-foot crossbraces or weight the bottom
of each leg.

## Supply

### honduras-rosewood-cites-lead-time
**Risk.** If a player overrides the Padauk default and chooses
Honduras Rosewood, the species is **CITES Appendix II** as of
2017. Sourcing with proper documentation is slow (60–120 days)
and expensive (~3× Padauk).

**Test.** If HR is selected, validate before order: supplier provides
CITES export permit number; cross-check against the CITES species
database. Pass = permit number valid and product description matches;
fail = no permit or mismatch — reject the order, fall back to Padauk.

## Fit/Finish

### tung-oil-finish-darkening-padauk
**Risk.** Padauk is naturally bright orange-red but oxidizes to a
deeper brown over months. Tung oil accelerates the oxidation. After
6–12 months bars look noticeably darker than at first build —
visual mismatch if a single bar is replaced later.

**Test.** Cut a 2"×2" Padauk swatch at the same time as the bars.
Apply same finish schedule. Store with the bars. After 30, 60, 180
days, photograph swatch under controlled light. Pass = expected
gradual darkening, no spotting or blooming; fail = uneven oxidation
patches — switch to a UV-blocking topcoat.

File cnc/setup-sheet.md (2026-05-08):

# Xylophone — CNC Setup Sheet

Pre-CAM operator-facing setup notes. Generates four operation groups
on the Maker Nexus ShopBot. **Bar work is explicitly out of scope** —
bars are bandsaw → plane → manual end-shave, never CNC.

## Machine

- **Machine:** Maker Nexus ShopBot 96"×60" CNC router.
- **Spoilboard:** 3/4" MDF, surfaced flat at session start.
- **Vacuum table:** Available for plywood operations only.

## Datum

Lower-left corner of stock for X/Y, top of stock for Z. **Same datum
for all four operation groups** — no re-zeroing between operations.
Use a touch plate for Z; manual probe to a corner pin for X/Y.

## Tooling

| Tool ID | Type | RPM | Used in |
|---|---|---|---|
| T01 | 1/4" 2-flute upcut compression | 16000  | OP1, OP4 |
| T02 | 1/8" 2-flute upcut | 18000  | OP2 |
| T03 | 1/2" 2-flute upcut | 14000  | OP3 |

Confirm bit length and stickout against the rail thickness (1.250")
before OP2 — a too-short bit will not clear the dado depth, a
too-long bit will gouge.

## Workholding

- **OP1 rails (hard maple, 22"×2.5"×1.5"):** Two toggle clamps and
  an L-fence on the back-left corner. Two through-holes per rail
  blank for safety screws into the spoilboard at the unused end.
- **OP2 rail-dado:** Same clamps as OP1 — do not break setup.
- **OP3 legs (hard maple, 32"×1.75"×1.75"):** One toggle clamp at
  each end; the legs are short enough that an L-fence is sufficient.
  Set fence parallel to X-axis.
- **OP4 gussets (Baltic birch, 12"×12"×0.5"):** Vacuum table only.
  Plywood is too thin to clamp without distortion. Confirm seal
  before any cut.

## Operation order

1. **OP1-rails** — outline both rails to final 21.0×2.25×1.25". Four
   passes at 0.3" per pass. Feed 90 in/min, RPM 16000.
2. **OP2-rail-dado** — keep T01 setup, swap to T02. Run a 0.125"-wide
   dado 0.250" deep along the inside top edge of each rail, full
   length, for the cord-stop pin to seat into. Feed 60 in/min, RPM
   18000.
3. **OP3-legs** — re-fixture for legs. Two 1.0"×0.5"×0.5" mortises
   per leg, top face, spaced to match the gusset edge. Feed 50
   in/min, RPM 14000.
4. **OP4-gussets** — vacuum table; one operation cuts all four
   gussets from one 12"×12" plywood blank. Each gusset is a
   45° right triangle with 6" legs.

## Per-operation release checks

Before pressing Cycle Start on each operation:

- [ ] Tool ID and offset matches the program.
- [ ] Stock dimensions verified at four corners with calipers.
- [ ] Datum (X0/Y0/Z0) verified by manual jog and feeler.
- [ ] Dry-run at Z+0.5" completed; toolpath visualizes correctly.
- [ ] Hold-down verified: clamps tight, or vacuum sealed.
- [ ] Dust collection on.
- [ ] Spotter present for first cut of each new operation.

After the first part of each batch:

- [ ] Pause the program.
- [ ] Measure critical dimensions (rail length, dado depth, mortise
      width, gusset hypotenuse) with calipers.
- [ ] Within ±0.005"? Resume. Else stop and re-cam.

## Pre-CAM assumptions

These four assumptions are stamped into the plan. If any one is
false on the day, **stop and re-plan** before cutting:

1. Stock thickness arrives within ±1/64" of nominal.
2. Hard maple is straight-grained and free of knots in the cutter
   path.
3. Plywood is B/BB or better with no voids in the cutter path.
4. Vacuum table seals on the 12×12 plywood blank without aux clamps.

## Post-CNC handoff

All four operation groups produce raw-cut parts. Hand-sand to 220
grit and break all edges 1/16" before frame glue-up. The frame
assembly continues at `assembly-manual.md` Step 8.

## Why no G-code yet

This is a pre-CAM plan. Actual G-code generation should run from a
CAM program (VCarve Pro is what Maker Nexus uses) against the
operation graph above plus the dimensioned drawings in `drawings/`.
The plan deliberately stops short of G-code so the operator catches
errors at CAM time, not at the spindle.

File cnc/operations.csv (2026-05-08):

op_id | sequence | part_id | operation | tool_id | feed_in_per_min | rpm | passes | workholding | datum | release_check
OP1-rails | 1 | FRAME-RAIL | outline rail to 21.0 x 2.25 x 1.25 in | T01 | 90 | 16000 | 4 | toggle-clamp+L-fence | lower-left+Z-top | verify rail thickness at 4 corners
OP2-rail-dado | 2 | FRAME-RAIL | 0.125 in dado along inside top edge | T02 | 60 | 18000 | 1 | toggle-clamp+L-fence | same as OP1 | confirm bit length and stickout
OP3-legs | 3 | FRAME-LEG | two mortises in top face per leg | T03 | 50 | 14000 | 1 | toggle-clamp | lower-left+Z-top | dry-run at Z+0.5 before first cut
OP4-gussets | 4 | FRAME-GUSSET | cut 4 triangle gussets from 12x12 plywood | T01 | 110 | 16000 | 2 | vacuum-table | lower-left+Z-top | confirm vacuum seal before through-cuts

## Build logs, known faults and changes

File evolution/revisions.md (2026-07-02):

# Revision Register — xylophone

| Rev | Date | Parent | Delta | Downstream artifacts invalidated |
| --- | --- | --- | --- | --- |
| A | 2026-07-01 | — | Stage 0 intake of current master (cad/xylophone.scad + xylophone-design-table.xlsx + xylophone-starter.wl). | none (no alpha/beta/production artifacts exist yet) |

Stage 0 only. Gate A has not been run; no Alpha compiles, vendor quotes, or production lock exist for this product.

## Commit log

2026-05-02 Initial scaffold: Xylophone
    [xylophone-design-table.xlsx]
2026-05-18 feat(learn-to-play): add xylophone starter songbook (#3)
    * feat(learn-to-play): add xylophone starter songbook (R4 claude-dan)
    Drop learn-to-play/ with 00-INDEX.md, scales/, fingerings/, and
    5 tunes (ABC + LilyPond + songsheet + notes). All tunes are
    public-domain traditional arrangements or original Heifer Zephyr
    compositions (MIT). Notation is at concert pitch; no external
    rendering tools required to read the ABC files.
    * fix: strip trailing whitespace from learn-to-play songsheets
    ---------
2026-05-18 Add Round 31 xylophone V5 gates (#5)
    [validation-loop.csv, visual-output-register.csv]
2026-05-20 Add xylophone DXF authority plan (#7)
    [per-bar-dxf-checklist.csv, validation-loop.csv, visual-output-register.csv]
2026-05-30 v5(xylophone): honest packet surface (Refs #6) (#8)
    [per-bar-dxf-authority-register.csv, v5-tier1-authority-gates.csv]
2026-05-31 wolfram-rename(xylophone): unique {slug}-starter.wl + dedupe + ref fixes (cloud-sync naming) (#9)
    [per-bar-dxf-checklist.csv, validation-loop.csv, visual-output-register.csv]
2026-05-31 Add image-gen concept prompt; wire explorer images
2026-06-21 Wire 3 rendered concept image(s) into explorer gallery
2026-06-23 feat(wolfram): deploy interactive model + live explorer embed (#11)
    * feat(wolfram): deploy interactive model + live explorer embed
    CloudDeploy Manipulate to Wolfram Cloud (Public-Execute); update
    explorer.html with live iframe. Refs tonykoop/instrument-maker#200
    * feat(wolfram): wire live explorer embed in explorer.html (Refs #200)
    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
2026-07-02 V5 packet refresh: status line, provenance, parametric OpenSCAD master, evolution intake
    - Set an honest Status line (repo had none): "L2 V5 build-packet candidate" —
    justified by the existing full design table, BOM, sourcing, cut-list, and
    validation-loop gates across all 25 bars (not concept-only), all still
    measurement_required per the repo's own "Round 31 V5 Build-Packet Gate".
    - Authored cad/xylophone.scad: parametric bar-length schedule (all 25 bars,
    dimensions taken directly from family-spec.csv) + trestle-frame envelope
    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
    [visual-output-register.csv, xylophone.scad]
